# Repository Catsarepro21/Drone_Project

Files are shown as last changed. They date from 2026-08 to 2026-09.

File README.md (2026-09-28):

# Autonomous Vision + FPV Quad

A hybrid carbon-fiber drone combining manual FPV controls with Raspberry Pi 5 onboard YOLO tracking and ArduPilot target following.
circuit_image

[https://app.cirkitdesigner.com/project/11a8d37d-fc97-4505-8930-f4c5d81e814d](https://app.cirkitdesigner.com/project/11a8d37d-fc97-4505-8930-f4c5d81e814d))
1 (1)

## Try It

* **Wiring Diagram:** [Cirkit Designer View](https://app.cirkitdesigner.com/project/11a8d37d-fc97-4505-8930-f4c5d81e814d)
* **BOM & Weight Calc:** [Google Sheet Breakdown](https://docs.google.com/spreadsheets/d/1xU_NW1MB9JgXXCRr1vzQk_ZqJNn86JdCjggnNsJFE8U/edit?usp=sharing)
## Quick Start

1. **Flash Flight Controller:** Upload ArduPilot (Copter firmware) onto the Cube Orange+ and calibrate IMU/compass.
2. **Setup Companion Computer:** Clone this repository onto the onboard Raspberry Pi 5 (8GB):
   ```bash
   git clone [https://github.com/Catsarepro21/Drone_Project.git](https://github.com/Catsarepro21/Drone_Project.git)
   cd Drone_Project

## Features

* Real-time target tracking via onboard YOLO inference running on a Raspberry Pi 5 over CSI.
* Automatic velocity and position command adjustments pushed to ArduPilot via MAVLink over serial (TELEM2).
* Dual HD video feed transmission (front GoPro Hero 6 & downward SJCAM) through Herelink v1.1.
* Dual power rail architecture designed to completely prevent Pi brownouts during heavy throttle spikes.
* Physical RC transmitter failsafe override to instantly revert from `GUIDED` mode to `POSHOLD` or `STABILIZE`.

## Local Simulation

1. Install [NVIDIA Isaac Sim](https://developer.nvidia.com/isaac-sim) (Linux environment recommended).
2. Follow the setup steps in the [Pegasus Simulator Installation Guide](https://pegasussimulator.github.io/PegasusSimulator/source/setup/installation.html).
3. Run the simulation environment to test flight dynamics and CV tracking algorithms:
   ```bash
   python3 pegasus_sim.py --config quad_yolo.yaml
   ```

## How It Works

Has both a FPV and an Autonomous mode powered by different controllers. To solve the issue where high motor current draws caused voltage sags and browned out the Raspberry Pi 5 during intense maneuvers, we completely separated the avionics and drive power rails. A primary 4S LiPo supplies the ESCs and 2820 1000kV motors, while a secondary 3S LiPo feeds an iFlight PD100W regulator to deliver a clean, continuous 5V/5A over USB-C to the companion computer.

## Authors & Acknowledgements

* **Authors:** [Rehan](https://stardance.hackclub.com/@rehanhabbu), [Sahlameer](https://stardance.hackclub.com/@Sahlameer), [Faahim](https://stardance.hackclub.com/@Faahim)
* **Open Source Tools:** [ArduPilot](https://ardupilot.org/), [Pegasus Simulator](https://pegasussimulator.github.io/PegasusSimulator/)

BOM:
| Quantity | Component Category | Item Name / Model | Est. Price (USD) | Purchase Link | Notes | Buy | Have |
|---:|:---|:---|:---|:---|:---|:---|:---|
| 1 | Flight Controller | CubePilot Cube Orange+ | $279.00 | [Link](https://www.getfpv.com/cubepilot-the-cube-orange.html) | Primary flight controller & autopilot | True | False |
| 1 | Flight Controller(Alternate) | CubePilot Cube Orange+ | $235.00 | [Link](https://ebay.com/used) | | True | False |
| 1 | Companion Computer | Raspberry Pi 5 - 8gb | $175.00 | [Link](https://www.canakit.com/raspberry-pi-5-8gb.html) | High-level vision processing & MAVLink control | False | True |
| 1 | Pi Front Camera Module | Sony IMX708 | $34.95 | [Link](https://www.canakit.com/raspberry-pi-camera-module-3.html) | Low-latency FPV / target tracking camera | True | False |
| 1 | Pi Down Camera Module | Arducam 5MP OV5647 | $28.99 | [Link](https://www.arducam.com/arducam-ultra-wide-angle-fisheye-5mp-ov5647-camera-for-raspberry-pi.html) | 220HFOV for Downward Facing Cam Detection | True | False |
| 1 | Streaming Cam Front | Go-Pro Hero 6 | $199.51 | [Link](https://www.walmart.com/ip/GoPro-HERO6-Black-4K-Action-Video-Camera/970674173) | 135FOV for streaming to controller | False | True |
| 1 | Streaming Cam Down | SJCAM SJ4000 | $55.99 | [Link](https://www.amazon.com/dp/B09GB1LN8V) | 170HFOV for streamign to controller | True | False |
| 1 | Air Unit / Telemetry | CubePilot HereLink HD Air Unit V1.1 | $851.58 | [Link](https://www.readymaderc.com/products/details/proficnc-herelink-air-unit) | HD video & MAVLink control link | False | True |
| 1 | GPS / Compass | Micro M10 GPS | $27.99 | [Link](https://holybro.com/products/micro-m10-gps?variant=42981482922173) | High-precision DroneCAN GPS/Mag - With Case and IST8310 | True | False |
| 1 | Main Battery | OVONIC 4S LiPo Battery 14.8V 6500mAh | $55.99 | [Link](https://www.amazon.com/dp/B0CP5GJM78) | 14.8V main power supply (NOTE: This is a 2-pack) | True | False |
| 3 | Electronics Battery | 3S 5000mAh 50C LiPo | $37.99 | [Link](https://hrb-power.com/products/11-1v-5000mah-6000mah-50c-trx) | Battery to power Auton Electronic Components | False | True |
| 1 | Power Distribution Board | Matek Systems PDB XT60 W | $0.99 | [Link](https://www.aliexpress.us/item/3256806070552817.html) | PDB for battery to ESC Transfer | True | False |
| 4 | ESC/s | BLHeli_S Series ESC 80A | $14.39 | [Link](https://www.aliexpress.us/item/3256811813844941.html) | Used to turn the Brushless motors, Rated for 80+ Amps ONLY | True | False |
| 4 | Brushless Motors | Skywalker 2820 SL motor -- 1000KV | $39.99 | [Link](https://www.hobbywingdirect.com/products/skywalker-2820-sl-motor?variant=41165095370867) | Quadcopter propulsion motors - ≤1000KV ONLY | True | False |
| 1 | Switch | XT60 Anti-Spark Electronic Switch | $9.17 | [Link](https://www.aliexpress.us/item/3256811379155381.html) | ONLY FOR AUTON ELECTRONICS | True | False |
| 1 | Power Module | Cube Power Brick Mini | $34.00 | [Link](https://nwblue.com/products/power-brick-mini?variant=42739874463897) | Current sensing & Cube power input | True | False |
| 1 | XT60 Splitter + USB | STRIX XT60 Power Hub with USB | $8.39 | [Link](https://www.aircraftpaintmasks.com/product/strix-xt60-power-hub-with-usb) | For Splitting xt60 and for usb power | True | False |
| 1 | XT60 USB converter | IFlight PD100W Adapter | $21.73 | [Link](https://www.aliexpress.us/item/3256808471582717.html) | For stable power to Go-Pro and Rpi-5 | True | False |
| 1 | XT60 USB converter | XT60 Plug to USB 5V Charger Converter Module Adapter | $9.99 | [Link](https://www.amazon.com/dp/B09BKWR4PP) | Power Source for SJ4k | True | False |
| 1 | Voltage Regulators | MATEK BEC12S-PRO | $14.08 | [Link](https://www.aliexpress.us/item/3256811890826612.html) | Clean voltage step-down for Herelink HD Air Unit | True | False |
| 1 | Ground Station | CubePilot HereLink Controller | $3,699.00 | [Link](https://irlock.com/collections/herelink) | Ground control transmitter & HD receiver | False | True |
| 1 | Propellers CCW | HQProp 12x4.5 CCW Propeller 2 PCS | $7.60 | [Link](https://www.readymaderc.com/products/details/85966-hq-prop-12x4-5-ccw) | HQProp 12x4.5 CCW Propeller 2 PCS -- 12in heavy lift | True | False |
| 1 | Propellers CW | HQProp 12x4.5 CW Pusher Propeller 2PCS | $3.80 | [Link](https://www.readymaderc.com/products/details/85965-hq-prop-12x4-5-cw) | HQProp 12x4.5 CW Propeller 2 PCS -- 12in heavy lift | True | False |
| 1 | Lock Nuts | Uxcell Nylon Insert Hex Lock Nuts | $6.60 | [Link](https://www.harfington.com/products/p-1794642?variant=48267773640953) | For Bushless motor threads so the props dont fall of in flight | True | False |
| 1 | Quad Copter Frame | Flyroun New F680 all carbon fiber | $65.27 | [Link](https://www.aliexpress.us/item/3256811746043574.html) | The Backbone of the Drone | True | False |
| 1 | AI Accelerator for PI | Ai Hat+ 26TOPS | $109.00 | [Link](https://www.microcenter.com/product/687348/product) | Maybe get it type item - if budget wills --For Extra Neural Processing | False | False |
| 1 | RGB Strip | 5V SK6812 RGB COB/FOB LED Strip Addressable | $7.18 | [Link](https://www.aliexpress.us/item/2255799861654620.html) | 🥀 144leds/m 0.5 black pcb ip67 waterproof | True | False |
| 1 | RGB Enclosure | Black 1m Aluminum enclosure with diffuser | $20.00 | [Link](https://www.amazon.com/dp/B07KBYQ3JR) | | True | False |

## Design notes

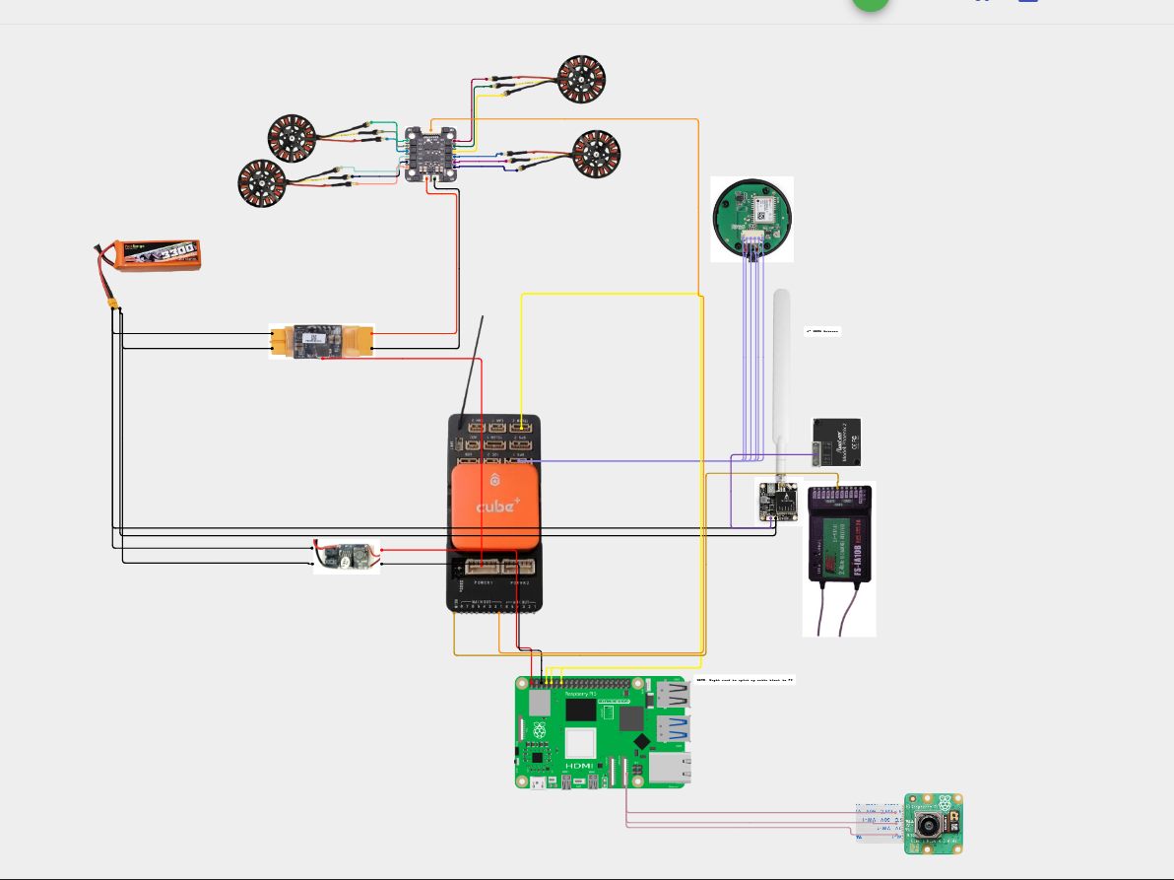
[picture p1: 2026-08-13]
docs/schematics/Circuit_Rev3.png

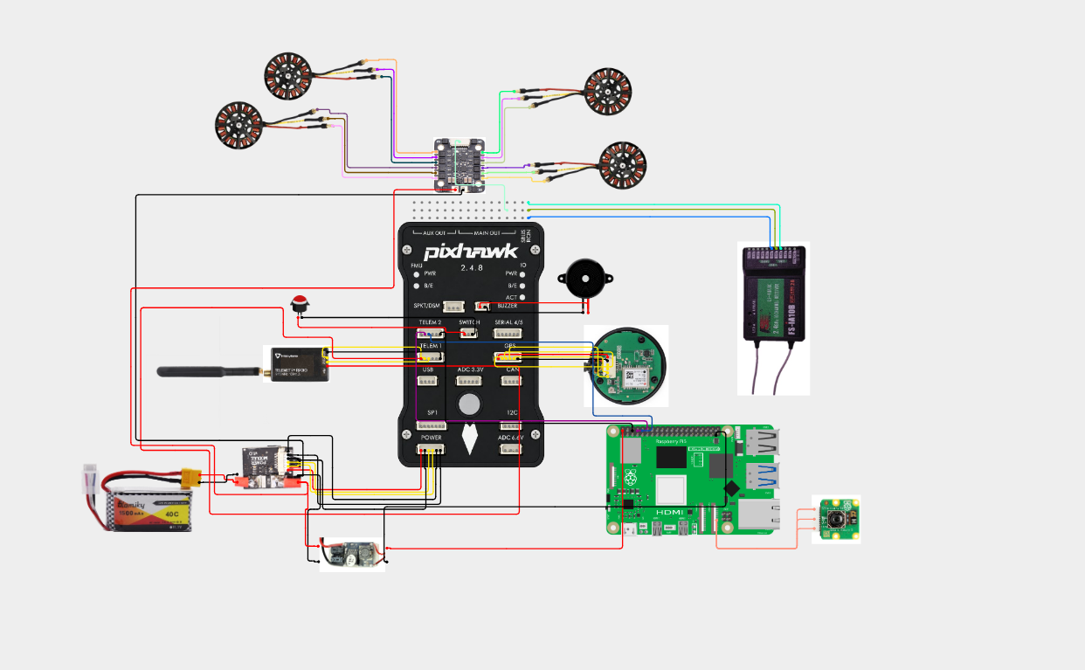
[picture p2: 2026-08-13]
docs/schematics/Circuit_Rev1.png

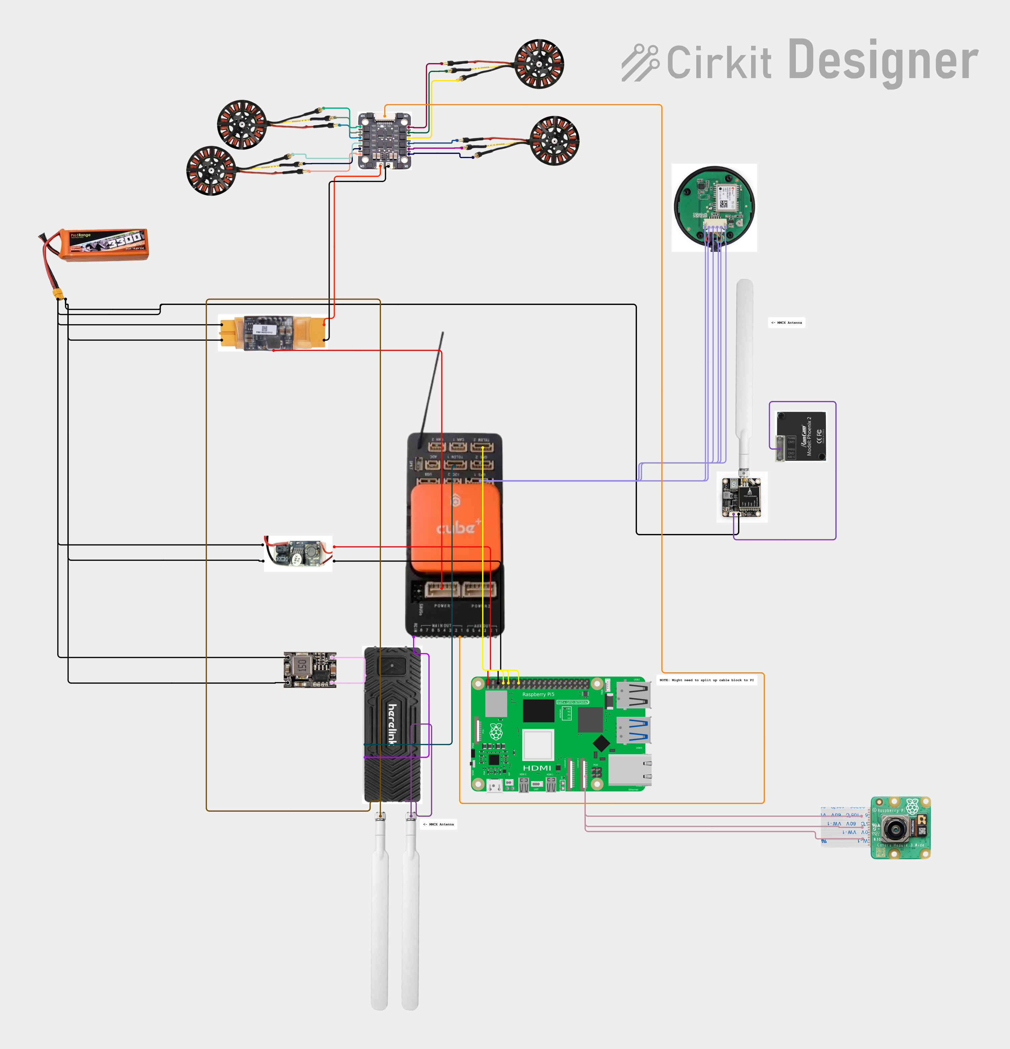
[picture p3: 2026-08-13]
docs/schematics/Circuit_Rev5.png

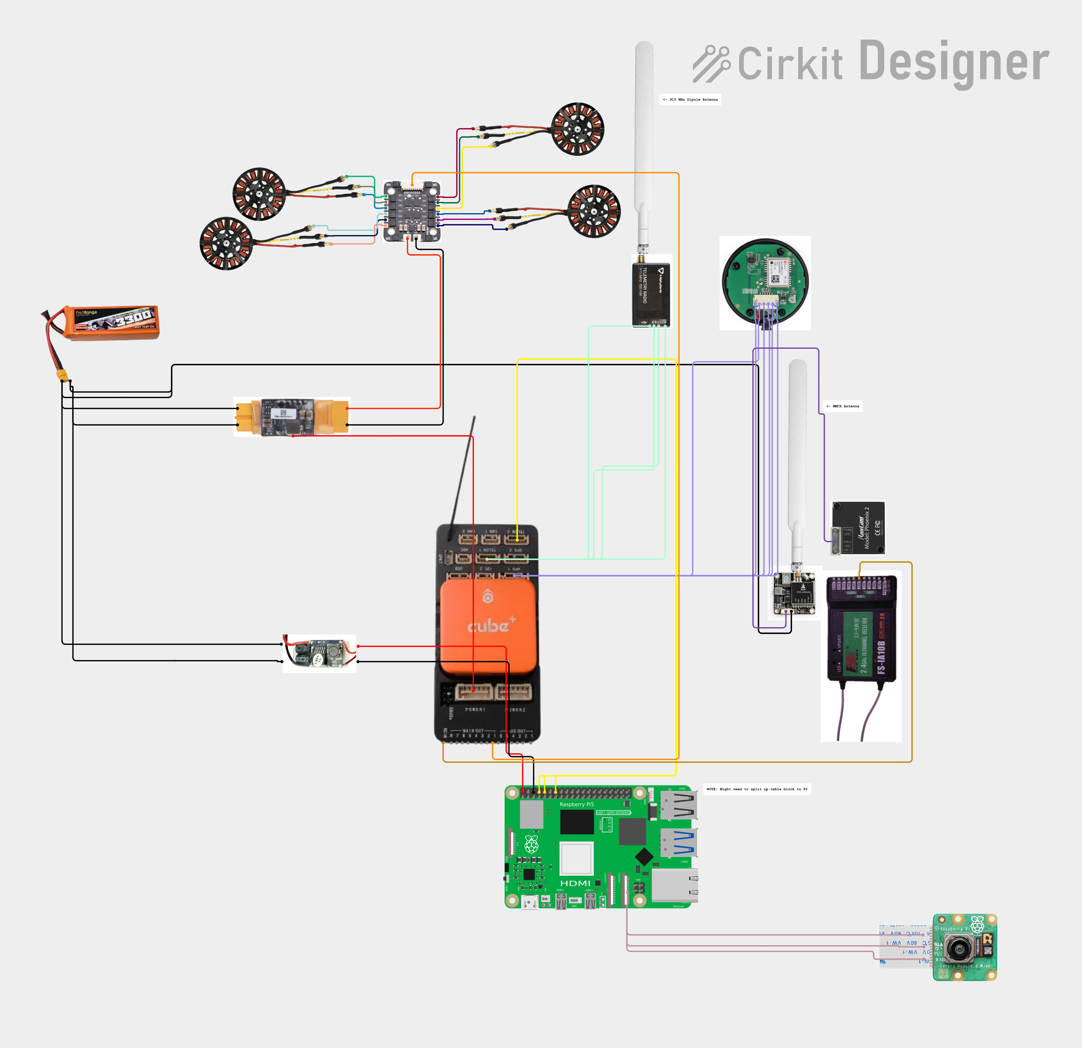
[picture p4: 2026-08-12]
docs/schematics/Circuit_Rev4.png

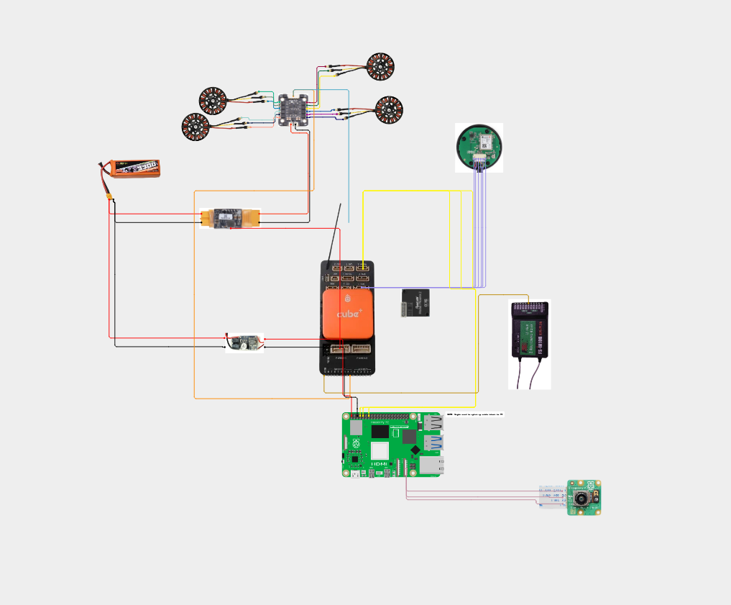
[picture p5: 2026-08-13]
docs/schematics/Circuit_Rev2.png

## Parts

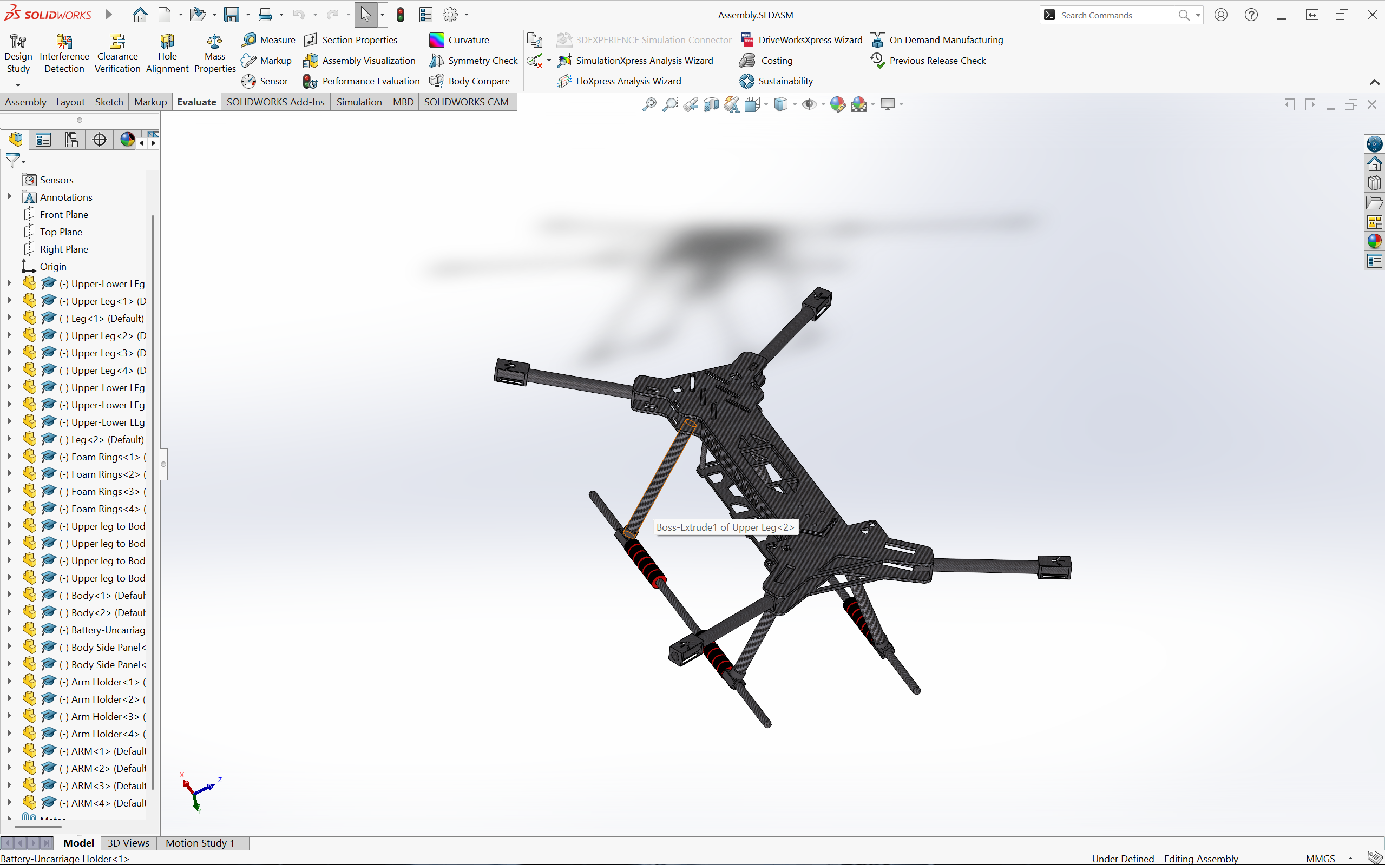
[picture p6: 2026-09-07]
Cad/Individual Parts/Screenshots/ScreenRecord/Screenshot 2026-09-07 142507.png

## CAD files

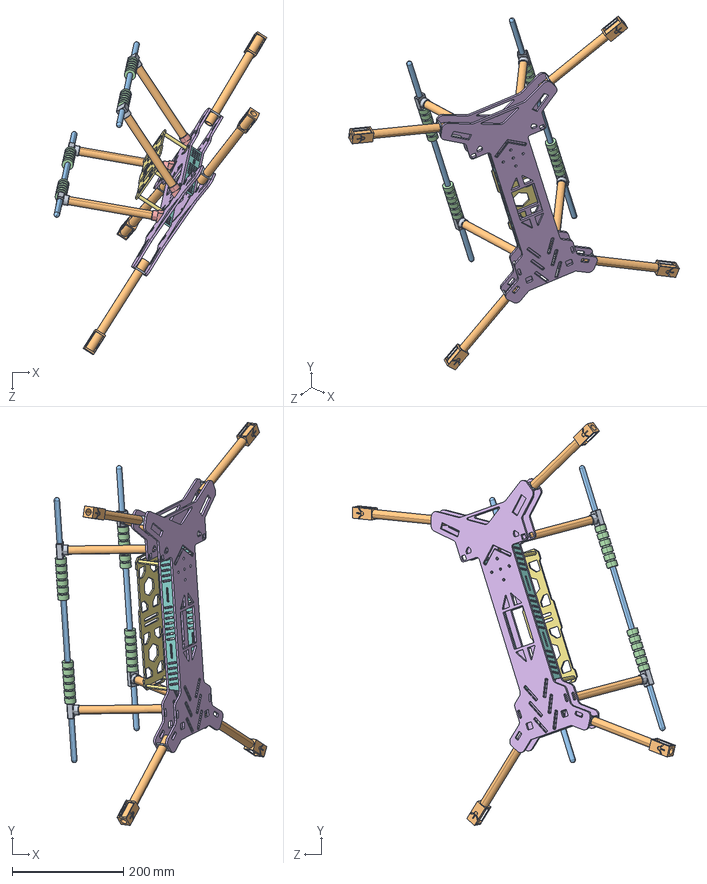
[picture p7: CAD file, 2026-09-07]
Cad/Individual Parts/Assembly/Assembly.STEP
382.8 x 724.9 x 580.6 mm
Upper-Lower LEg Connector x 4
Upper Leg x 4
Leg x 2
Foam Rings x 4
Upper leg to Body x 4
Battery-Uncarriage Holder
Body Side Panel x 2
Arm Holder x 4
ARM x 4

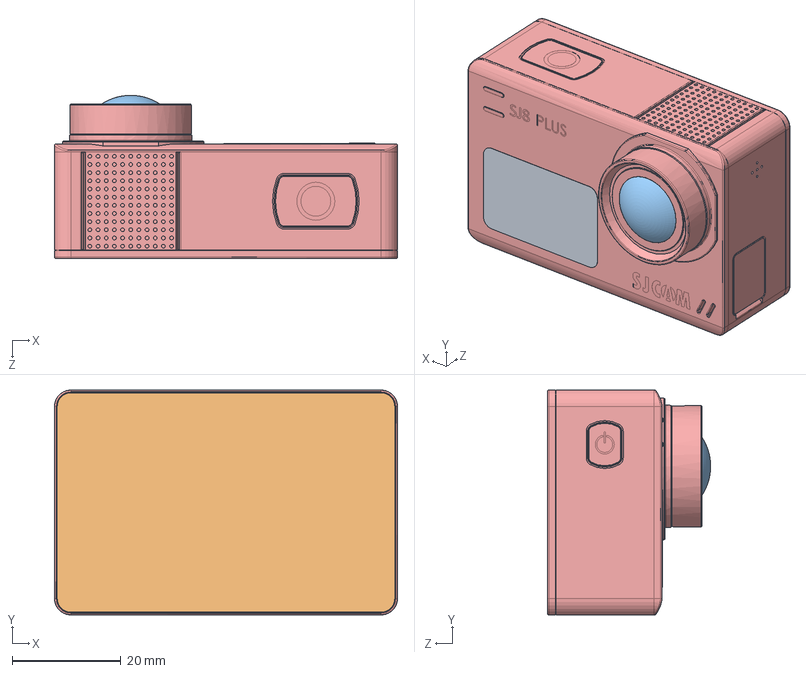
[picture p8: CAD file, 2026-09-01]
Cad/Individual Parts/SJCAM SJ4000/SJCAM.SLDASM
63.0 x 41.3 x 30.0 mm
corpo
lcd frente
lente
visor
visor frente

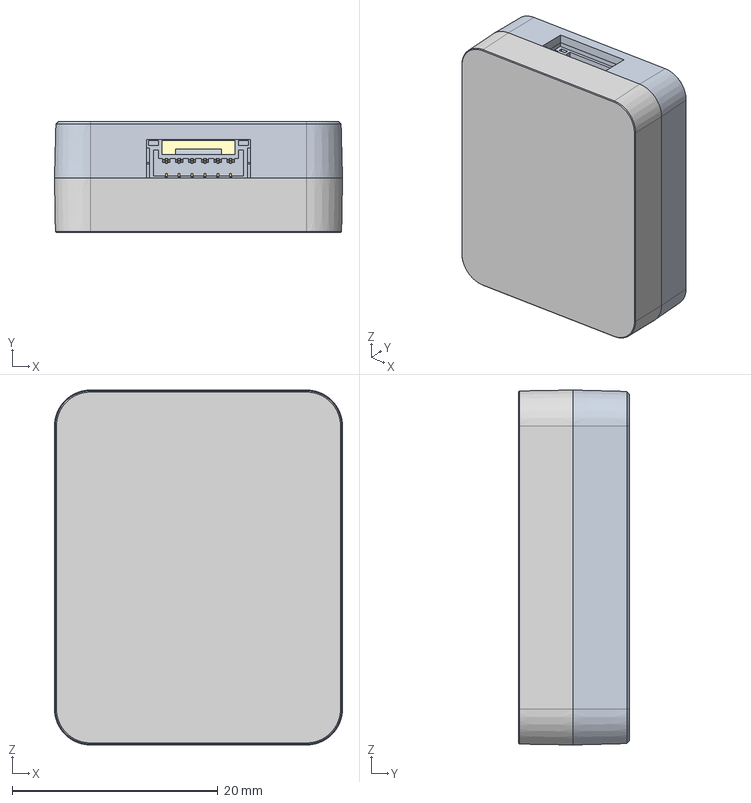
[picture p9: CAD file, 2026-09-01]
Cad/Individual Parts/micro-gps_asm.stp
28.0 x 10.8 x 34.5 mm
PCBA-GPS-M10
BM06B-WO-NEW
MIANKE-M10GPS-MUJ
DIKE-M10GPS-MUJU

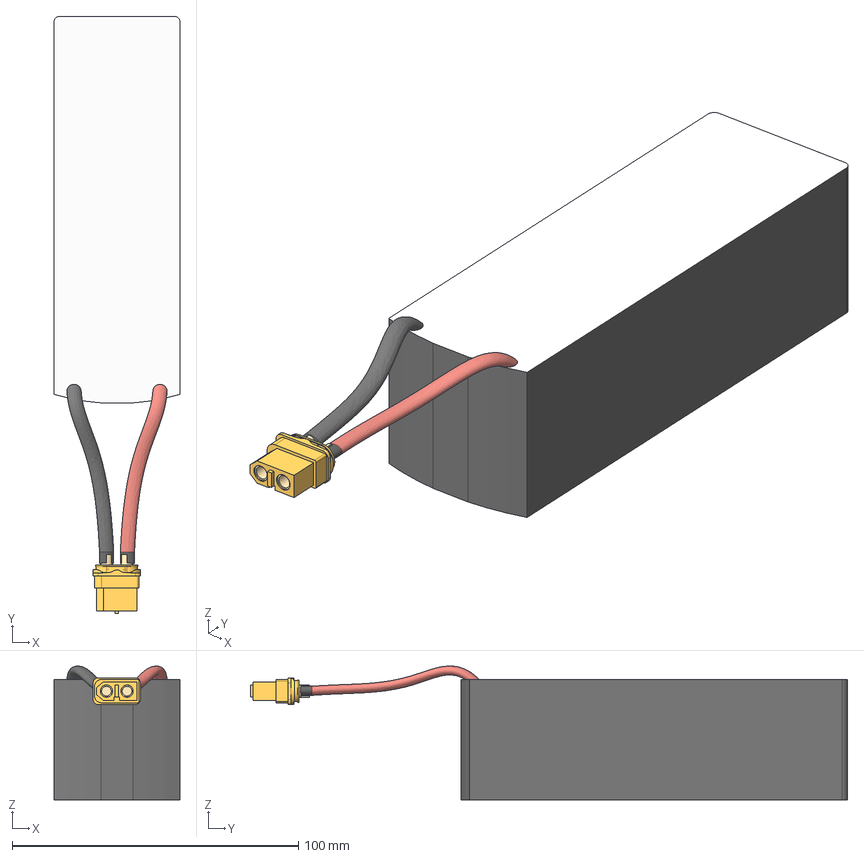
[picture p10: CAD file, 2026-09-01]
Cad/Individual Parts/Main Battery.step
44.0 x 208.6 x 46.8 mm
Housing
Contact x 2
Battery

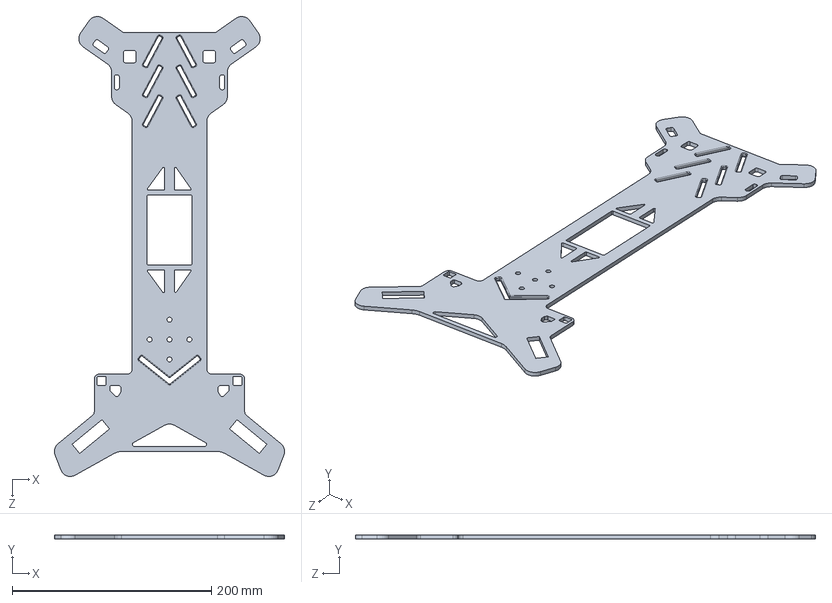
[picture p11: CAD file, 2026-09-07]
Cad/Individual Parts/Assembly/Frame/Body.SLDPRT
230.9 x 4.00 x 461.7 mm

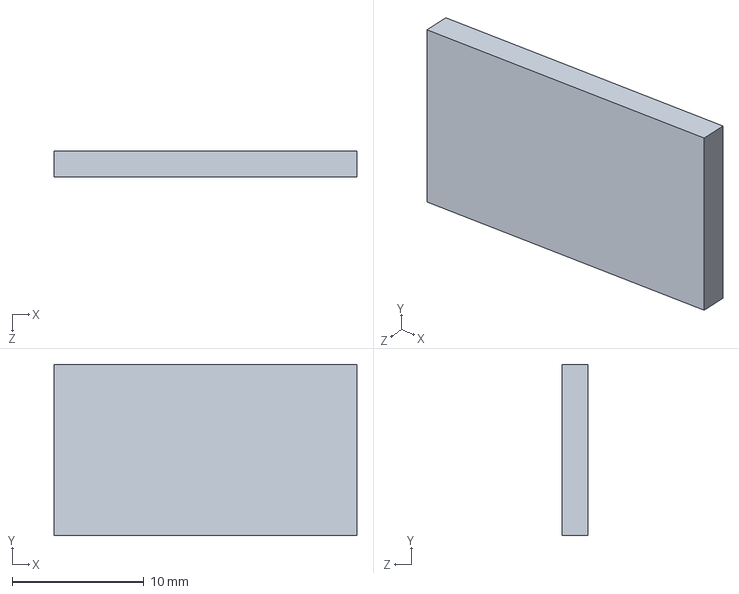
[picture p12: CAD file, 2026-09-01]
Cad/Individual Parts/SJCAM SJ4000/lcd frente.SLDPRT
23.0 x 13.0 x 2.00 mm

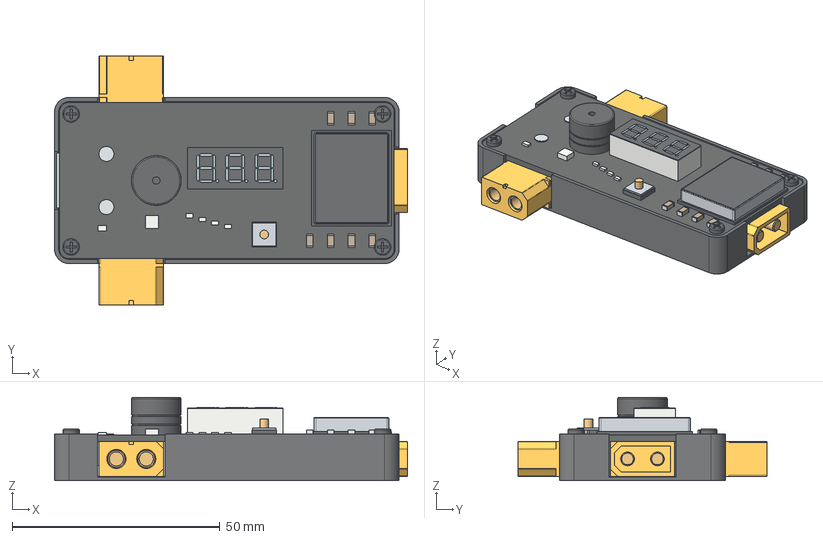
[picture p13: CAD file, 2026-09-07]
Cad/Individual Parts/STRIX_XT60_USB_reference.step
85.0 x 60.0 x 20.0 mm
01_case_external_and_assumed_closed_base
02_pcb
03_four_case_retaining_screws_unverified_pattern
04_XT60_output_left_housing
04_XT60_output_left_contacts_simplified
04_XT60_output_right_housing
04_XT60_output_right_contacts_simplified
05_XT60_input_housing
05_XT60_input_contacts_simplified
06_USB_A_shell
06_USB_A_insulator
06_USB_A_contacts
06_USB_anchor_solder_approx
07_buzzer
08_voltage_display_body
08_voltage_display_face
08_unlit_display_segments
09_regulator_module_base
09_regulator_shield
09_shield_dark_top_label
10_button_base
10_button_cover
10_button_actuator
11_ceramic_passives_approx
11_passive_terminations_approx
12_indicator_LED_packages_approx
12_auxiliary_white_package_approx

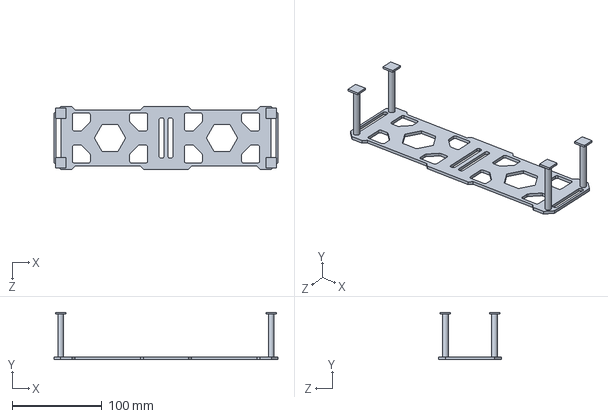
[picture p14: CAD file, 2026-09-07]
Cad/Individual Parts/Assembly/Frame/Battery-Uncarriage Holder.SLDPRT
250.0 x 53.0 x 70.0 mm

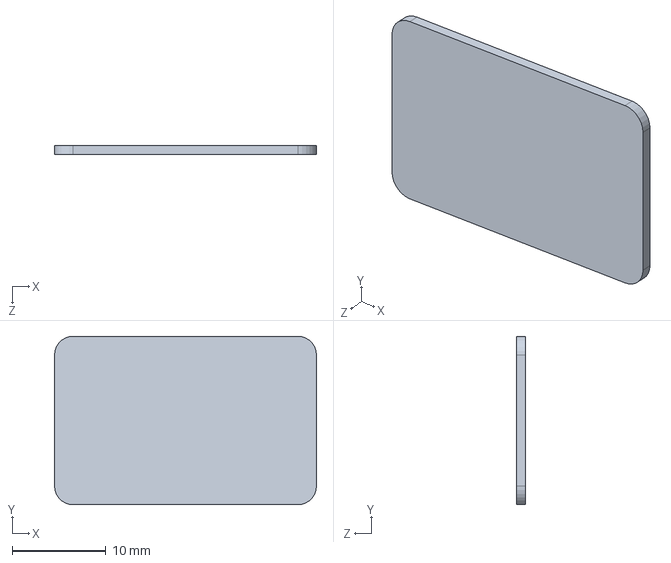
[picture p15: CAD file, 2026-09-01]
Cad/Individual Parts/SJCAM SJ4000/visor frente.SLDPRT
28.0 x 18.0 x 1.00 mm

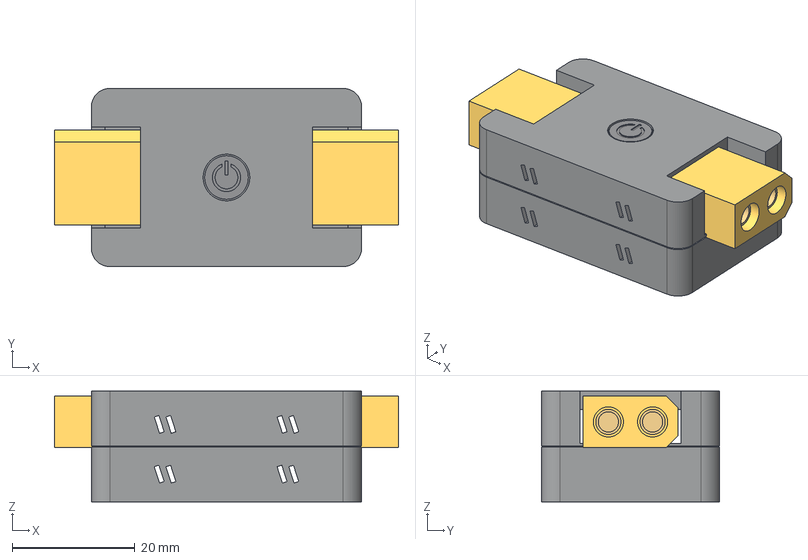
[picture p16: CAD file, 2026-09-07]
Cad/Individual Parts/XT60_Anti_Spark_Switch_Reference.step
56.0 x 29.0 x 18.0 mm
Lower_housing_estimated_holes_and_vents
Upper_housing_44x29x18_assumption
Recessed_power_button_estimated
Visible_bottom_heat_sink_estimated
Input_contact_-3.6
Input_contact_3.6
Input_XT60_approximate
Output_contact_-3.6
Output_contact_3.6
Output_XT60_approximate

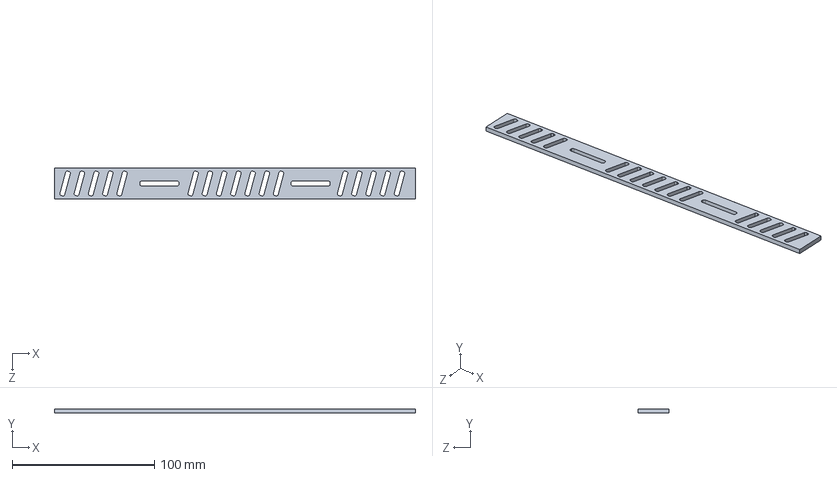
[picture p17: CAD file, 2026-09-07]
Cad/Individual Parts/Assembly/Frame/Body Side Panel.SLDPRT
253.7 x 3.00 x 22.0 mm

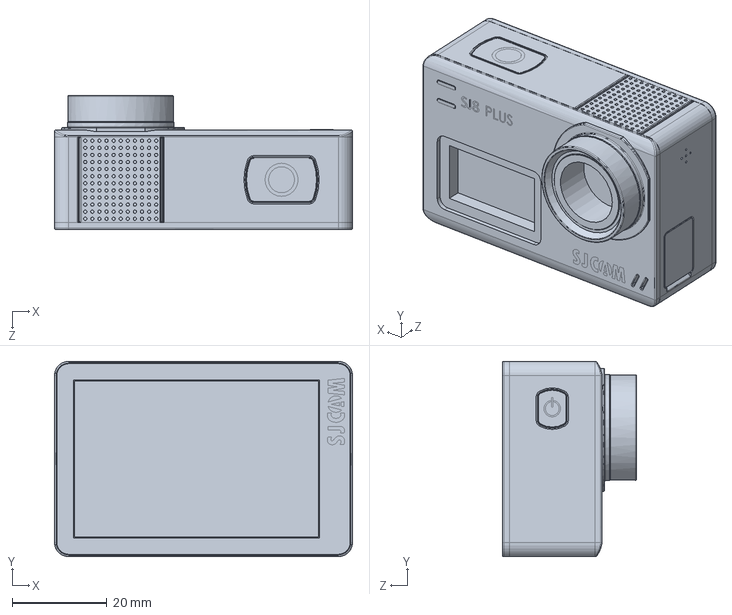
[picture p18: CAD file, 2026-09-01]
Cad/Individual Parts/SJCAM SJ4000/corpo.SLDPRT
63.0 x 41.3 x 28.4 mm

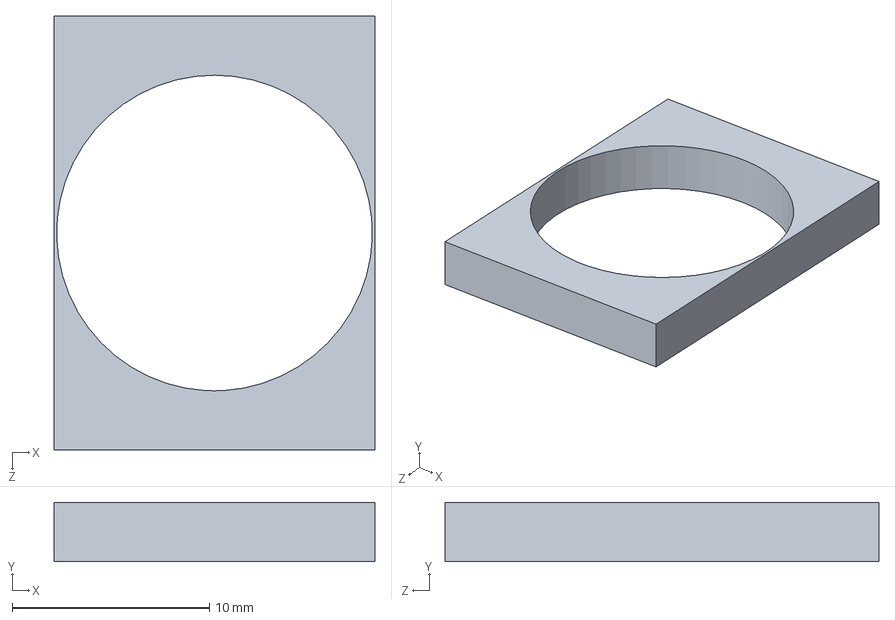
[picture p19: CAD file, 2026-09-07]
Cad/Individual Parts/Assembly/Frame/Arm Holder.SLDPRT
16.3 x 3.00 x 22.0 mm

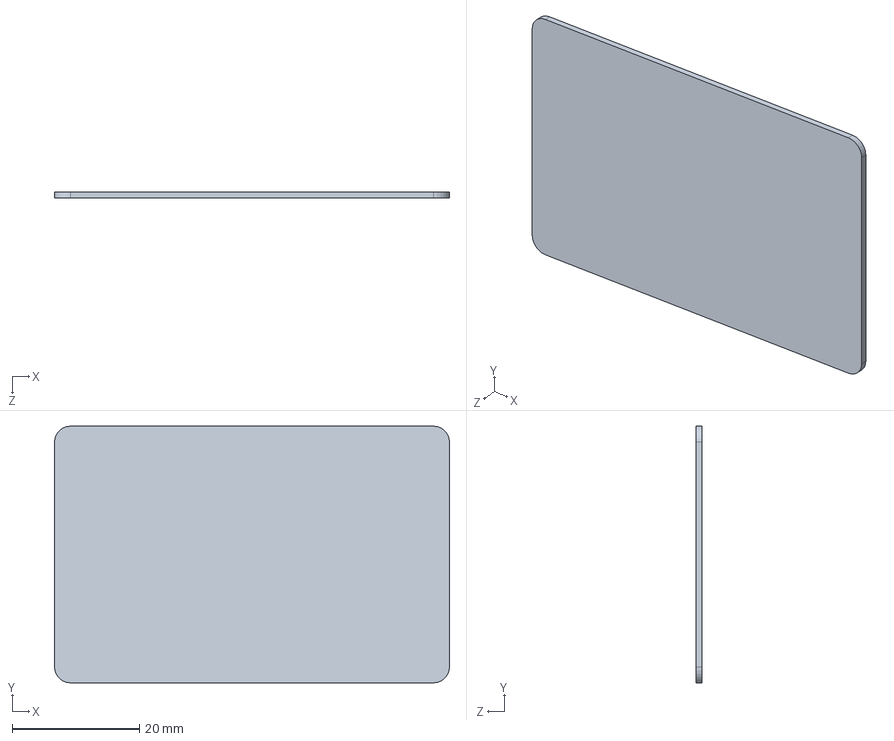
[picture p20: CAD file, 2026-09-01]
Cad/Individual Parts/SJCAM SJ4000/visor.SLDPRT
62.0 x 40.3 x 1.00 mm

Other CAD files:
Cad/Individual Parts/Sony IMX708 v8.step
Cad/Individual Parts/Assembly/Frame/ARM.SLDPRT
Cad/Individual Parts/HereLink Air Unit.STEP
Cad/Individual Parts/SJCAM SJ4000/lente.SLDPRT
Cad/Individual Parts/12x_4.ccwigs.STEP
Cad/Individual Parts/2820 Brushless Motor.step
Cad/Individual Parts/3s battery.STEP
Cad/Individual Parts/Assembly/Frame/Foam Rings.SLDPRT
Cad/Individual Parts/Assembly/Frame/Leg.SLDPRT
Cad/Individual Parts/Assembly/Frame/Upper Leg.SLDPRT
Cad/Individual Parts/Assembly/Frame/Upper leg to Body.SLDPRT
Cad/Individual Parts/Assembly/Frame/Upper-Lower LEg Connector.SLDPRT
Cad/Individual Parts/CUBE ORANGE PLUS.stp
Cad/Individual Parts/Gopro Hero 6.step
Cad/Individual Parts/Herelink Airunit Antenna.STEP
Cad/Individual Parts/M3 Nyloc Nut.step
Cad/Individual Parts/Matek Systems BEC12S PRO.stp
Cad/Individual Parts/PDB-TX60W.SLDPRT
Cad/Individual Parts/Power Brick Mini.STEP
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

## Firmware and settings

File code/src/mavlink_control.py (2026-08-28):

import time
import threading
from pymavlink import mavutil


class DroneController:
    def __init__(self, connection_string="/dev/ttyAMA0", baud_rate=921600):
        try:
            self.master = mavutil.mavlink_connection(connection_string, baud=baud_rate)
            self.master.wait_heartbeat(timeout=10)
        except Exception as e:
            print(f"[MAVLINK ERROR] Failed to establish connection: {e}")
            raise e

        self.target_system = self.master.target_system
        self.target_component = self.master.target_component

        self._lock = threading.Lock()
        self.armed = False
        self.current_mode = None
        self.local_position = None
        self.rangefinder_alt_m = None
        self._telemetry_stop = threading.Event()
        self._telemetry_thread = None

    def start_telemetry(self):
        self._request_message_interval(mavutil.mavlink.MAVLINK_MSG_ID_LOCAL_POSITION_NED, 10)
        self._request_message_interval(mavutil.mavlink.MAVLINK_MSG_ID_HEARTBEAT, 2)
        self._request_message_interval(mavutil.mavlink.MAVLINK_MSG_ID_DISTANCE_SENSOR, 10)

        self._telemetry_thread = threading.Thread(target=self._telemetry_loop, daemon=True)
        self._telemetry_thread.start()

    def stop_telemetry(self):
        self._telemetry_stop.set()
        if self._telemetry_thread is not None:
            self._telemetry_thread.join(timeout=2)

    def _request_message_interval(self, message_id, rate_hz):
        self.master.mav.command_long_send(
            self.target_system, self.target_component,
            mavutil.mavlink.MAV_CMD_SET_MESSAGE_INTERVAL,
            0,
            message_id,
            int(1e6 / rate_hz),
            0, 0, 0, 0, 0,
        )

    def _telemetry_loop(self):
        while not self._telemetry_stop.is_set():
            msg = self.master.recv_match(blocking=True, timeout=0.5)
            if msg is None:
                continue
            msg_type = msg.get_type()

            if msg_type == "HEARTBEAT":
                with self._lock:
                    self.armed = bool(msg.base_mode & mavutil.mavlink.MAV_MODE_FLAG_SAFETY_ARMED)
                    try:
                        self.current_mode = mavutil.mode_string_v10(msg)
                    except Exception:
                        self.current_mode = msg.custom_mode

            elif msg_type == "LOCAL_POSITION_NED":
                with self._lock:
                    self.local_position = (msg.x, msg.y, msg.z, msg.vx, msg.vy, msg.vz)

            elif msg_type == "DISTANCE SENSOR":
                with self._lock:
                    self.rangefinder_alt_m = msg.current_distance / 100.0

    def set_mode(self, mode_name):
        mode_mapping = self.master.mode_mapping()
        if mode_name not in mode_mapping:
            print(f"[MAVLINK ERROR] Unknown mode requested: {mode_name}")
            return False
 
        mode_id = mode_mapping[mode_name]
        self.master.mav.set_mode_send(
            self.target_system,
            mavutil.mavlink.MAV_MODE_FLAG_CUSTOM_MODE_ENABLED,
            mode_id,
        )
        return True
 
    def arm(self, wait_armed_timeout=10):
        self.master.mav.command_long_send(
            self.target_system, self.target_component,
            mavutil.mavlink.MAV_CMD_COMPONENT_ARM_DISARM,
            0,
            1, 0, 0, 0, 0, 0, 0,
        )
 
        deadline = time.time() + wait_armed_timeout
        while time.time() < deadline:
            with self._lock:
                if self.armed:
                    return True
            time.sleep(0.2)
        return False
 
    def auto_takeoff(self, target_altitude_m, wait_for_altitude=True, timeout=30):
        if not self.set_mode("GUIDED"):
            return False
        time.sleep(1)
 
        with self._lock:
            already_armed = self.armed
        if not already_armed and not self.arm():
            return False
 
        self.master.mav.command_long_send(
            self.target_system, self.target_component,
            mavutil.mavlink.MAV_CMD_NAV_TAKEOFF,
            0,
            0, 0, 0, 0, 0, 0,
            target_altitude_m,
        )
 
        if not wait_for_altitude:
            return True
 
        deadline = time.time() + timeout
        while time.time() < deadline:
            with self._lock:
                pos = self.local_position
            if pos is not None:
                alt_m = -pos[2]
                if alt_m >= target_altitude_m * 0.95:
                    return True
            time.sleep(0.2)
        return False
 
    def send_landing_target(self, angle_x, angle_y, distance=2.5):
        try:
            time_usec = int(time.time() * 1e6)
            self.master.mav.landing_target_send(
                time_usec,
                0,
                mavutil.mavlink.MAV_FRAME_BODY_NED,
                angle_x,
                angle_y,
                distance,
                0.0, 0.0,
                0.0, 0.0, 0.0,
                (1.0, 0.0, 0.0, 0.0),
                mavutil.mavlink.MAV_LANDING_TARGET_TYPE_VISION_FIDUCIAL,
                1,
            )
        except Exception as e:
            print(f"[MAVLINK WARN] Failed to send landing target packet: {e}")
 
    def get_position_hold_feedback(self, vel_tolerance_ms=0.15):
        with self._lock:
            pos = self.local_position
            alt_rf = self.rangefinder_alt_m
 
        if pos is None:
            return {"valid": False}
 
        x, y, z, vx, vy, vz = pos
        horizontal_speed = (vx ** 2 + vy ** 2) ** 0.5
        stable = horizontal_speed <= vel_tolerance_ms
 
        return {
            "valid": True,
            "stable": stable,
            "horizontal_speed_ms": horizontal_speed,
            "vertical_speed_ms": vz,
            "altitude_m": -z,
            "rangefinder_altitude_m": alt_rf,
        }
 
    def land_here(self):
        return self.set_mode("LAND")
 
 
if __name__ == "__main__":
    import argparse
    from vision import VisionTracker, MODE_LOCAL, MODE_REMOTE
 
    parser = argparse.ArgumentParser()
    parser.add_argument("--connection", default="/dev/ttyAMA0")
    parser.add_argument("--baud", type=int, default=921600)
    parser.add_argument("--vision-mode", choices=[MODE_LOCAL, MODE_REMOTE], default=MODE_LOCAL)
    parser.add_argument("--takeoff-alt", type=float, default=5.0)
    args = parser.parse_args()
 
    drone = DroneController(args.connection, args.baud)
    drone.start_telemetry()
 
    vision = VisionTracker(mode=args.vision_mode)
 
    try:
        drone.auto_takeoff(args.takeoff_alt)
 
        landed = False
        while not landed:
            _frame, angle_x, angle_y, distance, found = vision.process_frame()
 
            if found:
                drone.send_landing_target(angle_x, angle_y, distance or 2.5)
 
                feedback = drone.get_position_hold_feedback()
                if feedback["valid"] and feedback["stable"] and feedback["altitude_m"] < 1.0:
                    drone.land_here()
                    landed = True
 
            time.sleep(0.05)
 
    except KeyboardInterrupt:
        pass
    finally:
        vision.release()
        drone.stop_telemetry()

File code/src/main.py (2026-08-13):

import sys
import cv2
from vision import VisionTracker
from mavlink_control import DroneController
import numpy as np

SIMULATION_MODE = True 

if SIMULATION_MODE:
    CONNECTION_STRING = 'udp:127.0.0.1:14550'
    BAUD_RATE = 115200
else:
    CONNECTION_STRING = '/dev/ttyUSB0'
    BAUD_RATE = 921600

def main():
    drone = DroneController(CONNECTION_STRING, BAUD_RATE)
    tracker = VisionTracker(is_sim=SIMULATION_MODE)

    print("[System] Starting main loop. Press 'q' to exit.")
    dummy_frame = 225 * np.ones((480, 640, 3), dtype=np.uint8)

    while True:
        if SIMULATION_MODE:
            frame, offsets, found = tracker.process_frame(dummy_frame)
        else:
            frame, offsets, found = tracker.process_frame()
        if frame is None:
            continue
        if found:
            angle_x, angle_y = offsets
            drone.send_landing_target(angle_x, angle_y)
        cv2.imshow("Computer Vision Feed", frame)
        if cv2.waitKey(30) & 0xFF == ord('q'):
            break

    tracker.release()
    cv2.destroyAllWindows()

if __name__ == "__main__":
    main()
        

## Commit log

2026-08-11 Update README with project title and link
    Added project title and wiring diagram link to README.
2026-08-12 Update wiring diagram link in README.md
2026-08-12 Fix link formatting in README
    Updated the link formatting for the wiring diagram.
2026-08-12 Add initial content to CAD file
2026-08-12 Rename HereLink Antenna.step to cad/HereLink Antenna.step
    [HereLink Antenna.step]
2026-08-13 Add new circuit schematics: Circuit_Rev4.png and Circuit_Rev5.png
2026-08-13 Create sample Vision.py
2026-08-13 Created sample mavlink_control.py
2026-08-13 Fix Mavlink_control.py to use correct normalized FOV angle calculation and remove unnecessary comments in vision.py. Updated requirements.txt to include necessary dependencies.
    [mavlink_control.py]
2026-08-13 Create Sample main.py
2026-08-14 Tracked Battery Discharge Graph and Flight Time Results from EveryDrone
2026-08-16 Add alternate S500 Cad File
    [S500-Straigh_Legs.step]
2026-08-19 Enhance DroneController with telemetry and threading
    Refactor DroneController to include threading for telemetry and improve connection handling.
2026-08-19 Update README with additional note on pre-arm status
    Clarify instructions for arming and autonomous takeoff.
2026-08-27 Update README with BOM and weight link
    Added link to detailed BOM and weight information in README.
2026-08-28 Individul parts minus the frome for Drone Assmebly
    [12x_4.ccwigs.STEP, 2820 Brushless Motor.step, 3s battery.STEP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]
2026-09-01 Update BOM
    [BOM.csv, Drone Project BOM - BoM.csv]
2026-09-01 Update Drone Project BOM with new quantities and links
    [Drone Project BOM - BoM.csv]
2026-09-01 Revise Drone Project BOM with new items and quantities
    Updated the Drone Project BOM by adding new components and adjusting quantities.
    [Drone Project BOM - BoM.csv]
2026-09-01 Update Drone Project BOM with new components
    [Drone Project BOM - BoM.csv]
2026-09-01 Revise Drone Project BOM with updated quantities
    Updated quantities and added notes for several components in the BOM.
    [Drone Project BOM - BoM.csv]
2026-09-01 Update Drone Project BOM with new entries and prices
    [Drone Project BOM - BoM.csv]
2026-09-01 Rename Drone Project BOM - BoM.csv to BoM.csv
    [BoM.csv]
2026-09-01 Create BOM.md with clickable links for components
    Added a detailed bill of materials (BOM) with clickable links for various components, including prices and notes.
2026-09-01 Rename BOM.md(Clickable Links) to BOM(Clickable_Links).md
2026-09-01 Update README.md and add Final Circuit design Schematic.svg
2026-09-02 Update README with wiring diagram link
    Added wiring diagram link to README.
2026-09-04 Added parts and assembly for Drone Frame
    [Assembly.SLDASM, Body.SLDPRT, Foam Rings.SLDPRT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]
2026-09-07 Finished the frame model without any parts on it.
    [ARM.SLDPRT, Arm Holder.SLDPRT, Assembly.SLDASM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]
2026-09-07 Converted assembly to .step file
    [Assembly.STEP]
2026-09-28 Update schematic image link in README
    Fixed the image link for the schematic in the README.
2026-09-28 Update README with correct image and link formatting
    Fix image syntax and update schematic link in README.
2026-09-28 Add BOM section to README
    Added a Bill of Materials (BOM) section with detailed components, prices, and links.
